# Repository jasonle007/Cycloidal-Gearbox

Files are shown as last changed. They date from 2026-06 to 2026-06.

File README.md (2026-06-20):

# Cycloidal-Gearbox
Documentation of the engineering design process of building a cycloidal drive. From idea, constraints, CAD, prototyping, and manufacturing the final product




## Design Requirements
The cycloidal drive project started as a project for my research lab (CoRE) where I am working to build a medical apparatus to experiment with human propioception. The device needed a strong motor/gearbox capable of producing enough torque to life a human leg from the sitting position, as well as the standing position.

Constraints included:
  - High torque capable of liting a human leg
  - Quiet gear box
  - Compact design
  - Minimal backlash
  - Durable

This led to the cycloidal drive design, which sastisfied these constrains and after discussions with my PI, gained approval for me to start researching and developing the drive.

## Design Process

### Cycloid Profile Generation
The cycloidal disk geometry was generated using standard cycloidal equations referenced from this SOLIDWORKS article [Building-a-Cycloidal-Drive](https://blog-assets.solidworks.com/uploads/sites/3/Building-a-Cycloidal-Drive-with-SOLIDWORKS.pdf).

The 4 main parameters were:

- Roller count (N) = 17
- Roller radius (Rr) = 6mm
- Rotor radius (R) = 50mm
- Eccentricity (E) = 1.8mm

With assistance from Claude, multiple geometries were evaluated to balance:
- Torque capacity
- Manufacturability
- Smooth operation

Cycloidal gear profile generation 133200


Based on the profile of the drive set by these parameters, they would define the rest of the assembly: housing, eccentric shaft, and output disk.

Note: This cycloidal drive design will utilize 2 cycloidal gears off set 180 from each other to balance out eccentric forces. Hence the need for an indicator of somekind 

### Housing
The housing would encase the entire assembly and roller pins for the gear profiles to engage with.

The roller pins with have a radius of 6mm and sit on a construction circle equal to the rotor radius of 50mm. These were the 2 critical dimensions for the housing and the rest of the design focused on fully encasing the assembly along with screw and threaded insert holes.



### Eccentric Shaft
The eccentric shaft's function is to engage the cycloidal profile with the roller pins. Creating the gear reduction and inverse rotation for the output pins.

The critical dimesions of the shaft is the eccentricity made by offsetting the center of the journal profile by 1.8mm. For this cycloidal drive design, the 2 cycloidal gears will sit 180 degrees offsetted from each other to cancel out the eccentric forces and reduce vibrations.



The red marks show the 1.8mm offset and in the center, both eccentric sections are offsetted by a total of 3.6mm. The shaft was designed to be printed in 3 seperate sections and joined together with 2 M4 screws traveling through the entire shaft. Shaft features raised borders to seperate each section and the shaft diameter was toleranced to be 19.9mm, which gives a snug fit of 0.1mm with the bearing.

### Output Disk
The output disk consists 2 sections joined together by screws and bearings to form the gear assembly. The output disk house the output pins whihc slots through output holes of the cycloid gear and transmit the gear's internal rotation into output torque. The first section is the base, where the input side sits and the second section is the cap where the output is transmitted.

The critical dimensions consist of the output pin diameter and the output pin construction circle, which can be set independently to the 4 main paramenters.





Both disks features a compliance cut around the center hole to give way to tight tolerances, reducing contact points and introducing flex to the contact, allowing for more forgiving fits of the output bearings. Additionally, threaded insert holes are modelled in for secure screw connections and repeatability.

## Key Engineering Challenges

### Bearing Fit
Initial prototypes produced undersized bearing bores due to PETG dimensional inaccuracies.

Solutions:
- Adjusted hole clearances
- Added compliance slots
- Tuned slicer XY compensation
- Performed iterative print testing

### Output Pins
Several output pin clearances were evaluated to reduce binding while minimizing backlash.

The final design calculated the output pin holes to be the (diameter + 2*eccentricity) to provide minimal backlass. Testing showed that approximately 0.2 mm radial clearance provided reliable operation. 

## Manufacturing

### Processes

- FDM 3D Printing with:
  - Prusa i3 MK3s+
  - PETg filament
 
- Slicing
  - XY - compensation to account for hole shrinkage as filament expands. In my case a value of -0.15mm worked best to pull back the walls of the holes by a diameter of 0.3mm, since past prototype prints would result in a hole shrinkage of 0.3mm
  - Elephant compensation to account for first layer filament spread. The first layer expanded roughly about 0.15mm outwards from the rest of the print, so the default value of 0.20mm worked best when printing PETg
 
### BOM
| Item | Note | Quantity | Price  | Total | Link |
| --- | --- | --- | --- | --- | --- |
| PETG Filament | Stronger and more secure structure | 2 | $0.00  | $0.00 | Already have |
| Shaft Bearings (20mm ID × 32mm OD × 10mm W, 10-pack) | For cycloid rotors and output disk (4) | 1 | $12.29 | $12.29 | [Link](https://www.amazon.com/uxcell-6804ZZ-Groove-Bearings-Shielded/dp/B082PWB7R5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) |
| Roller Bearings (4mm ID × 12mm OD × 4mm W, 20-pack) | For rollers (34) and output disk pins (12), 46 total  | 3 | $9.99  | $29.97 | [Link](https://www.amazon.com/uxcell-6804ZZ-Groove-Bearings-Shielded/dp/B082PWB7R5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) |
| Output Disk Bearings (35mm ID × 62mm OD × 14mm W, 2-pack) | For output disk to housing (2) | 1 | $9.99  | $9.99 | [Link](https://www.amazon.com/HiPicco-6007-2RS-Bearings-Bearing-Pre-Lubricated/dp/B0CH2WVW4V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) |
| M4 × 40mm Phillips Head Screws (15-pack) | For output disk pins (6) | 1 | $5.97  | $5.97 | [Link](https://www.amazon.com/Machine-Stainless-Assortment-Phillips-Furniture/dp/B0DLGT59V3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) |
| M4 × 65mm Hex Screws (10-pack) | For eccentric shaft (2) and housing cap (8), 10 total | 1 | $5.00  | $5.00 | [Link](https://www.amazon.com/Stainless-Machine-Hexagon-Fastener-Quantity/dp/B0CG1NMPCT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) |
| 4mm × 60mm Dowel Pins (20-pack) | For rollers (17) | 1 | $8.49  | $8.49 | [Link](https://www.amazon.com/uxcell-Cylindrical-Mechanical-Manufacturing-Installation/dp/B0DRSK8KVQ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) |
| M4 × 5mm L × 6mm OD Threaded Inserts (50-pack) | Inserts for housing and output disk connection (16) | 1 | $7.69  | $7.69 | [Link](https://www.amazon.com/uxcell-Knurled-Printing-Threaded-Embedment/dp/B0CTCT5TXZ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) |
| **Grand Total** | | | | **$79.40** | |

With filament supplied from the lab, the rest of the components came out to a total of $79.40. Added in extra costs of manufacturing and prototyping, this brings the total for this cycloidal drive to under $100. Note that many of these components are bought with higher quanities than needed so to build a second drive would only need a feew extra orders, bringing the projected cost of 2 fully assembled cycloidal drive to under $200.



## Results
- Reduction ratio: 17:1
- Maximum output torque: 40-50 Nm
- Number of design iterations: 20+
- Material: PETG
- Print time: 40+ hours (inclduing prototyping)

## Future Improvements
- Prototype with PLA and reduced infill
- Reduce housing wall width
- Finite element analysis
- Interference detection analysis

## Lessons Learned
This project strengthened my understanding of:

- Tolerance stack-up
- Design for additive manufacturing
- Bearing and shaft fits
- Iterative prototyping
- Mechanical power transmission
- Engineering tradeoff analysis

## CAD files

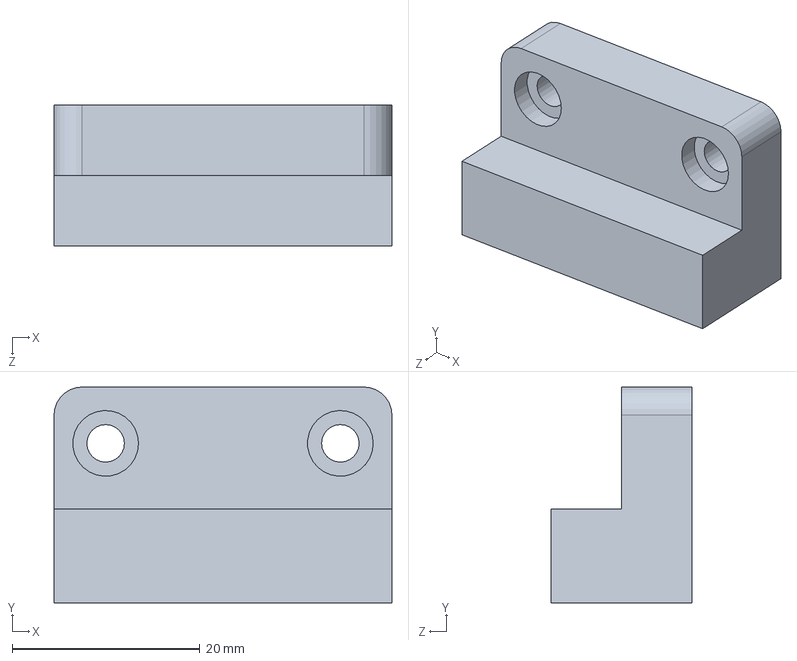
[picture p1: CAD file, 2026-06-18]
CAD/MotorMount.SLDPRT
36.0 x 23.0 x 15.0 mm

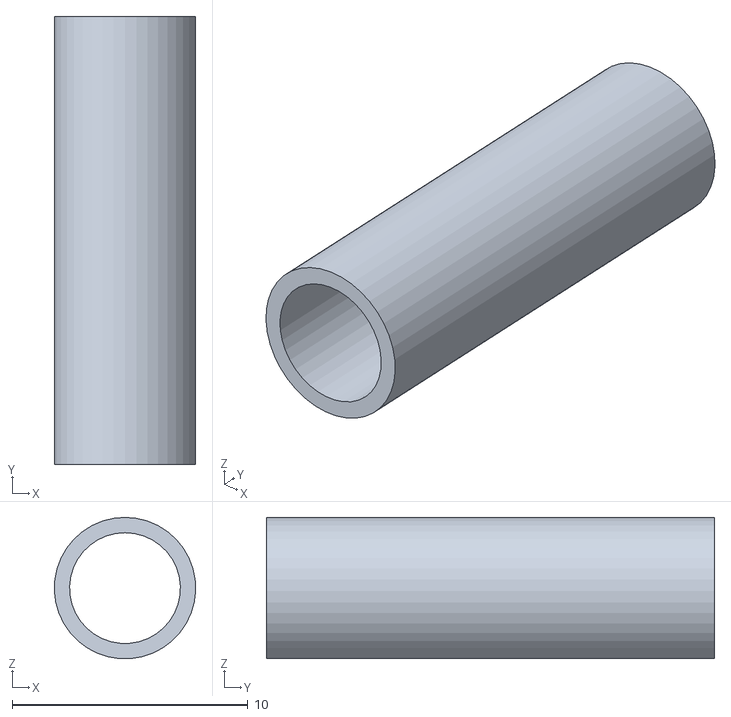
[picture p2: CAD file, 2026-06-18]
STL/Top Roller Spacers.STL
6.00 x 19.0 x 5.99

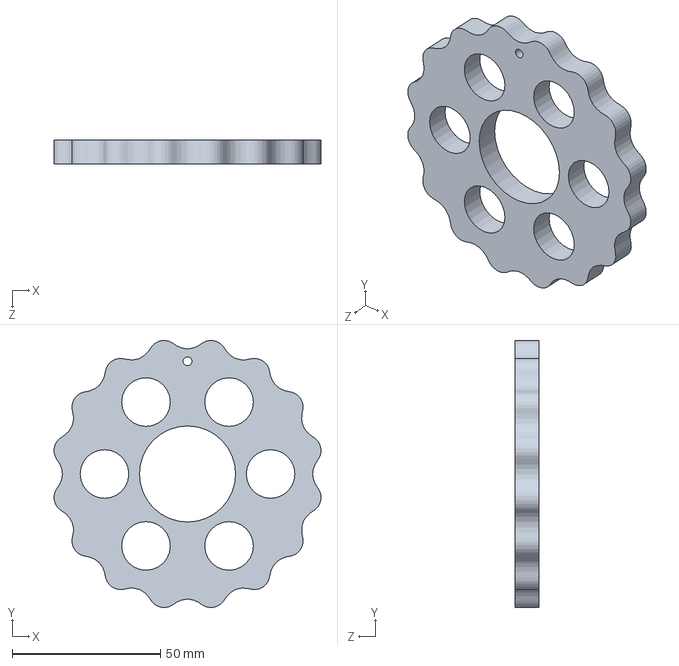
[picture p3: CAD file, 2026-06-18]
CAD/Cycloidal Internal Rotor.SLDPRT
90.0 x 90.0 x 8.00 mm

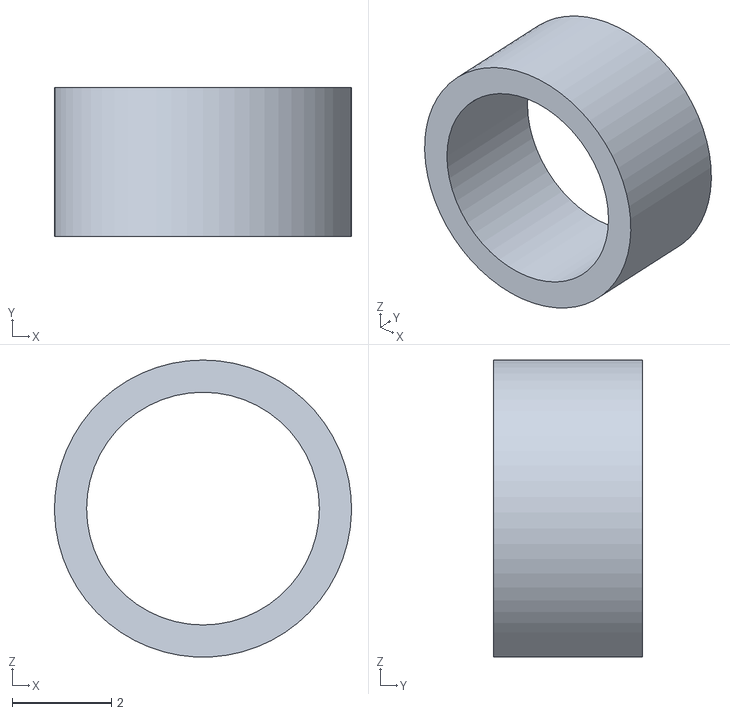
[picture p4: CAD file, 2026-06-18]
STL/3mm Output Disk Spacers.STL
6.00 x 3.00 x 6.00

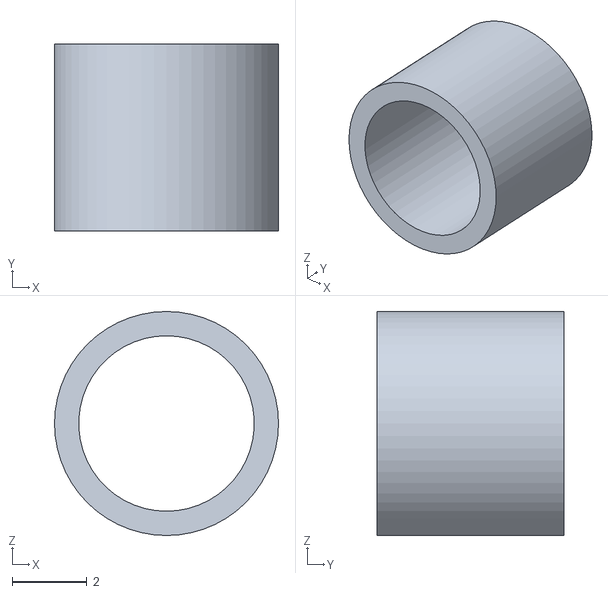
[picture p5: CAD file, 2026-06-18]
STL/5mm Output Disk Spacers.STL
6.00 x 5.00 x 6.00

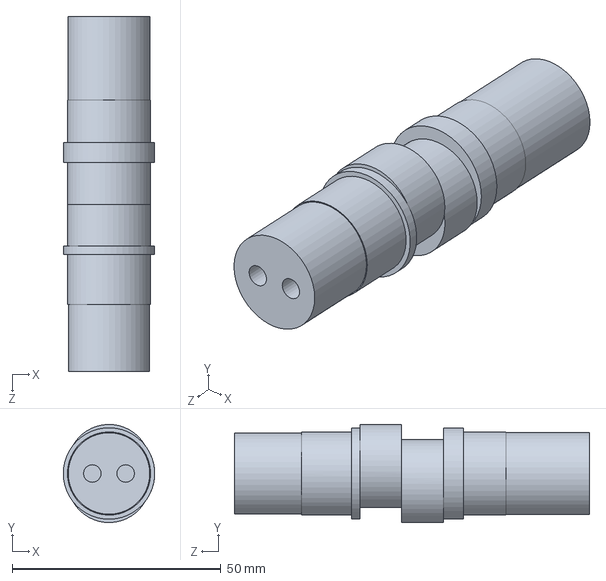
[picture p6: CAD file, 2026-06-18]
CAD/Eccentric Shaft.SLDPRT
21.9 x 23.5 x 85.0 mm

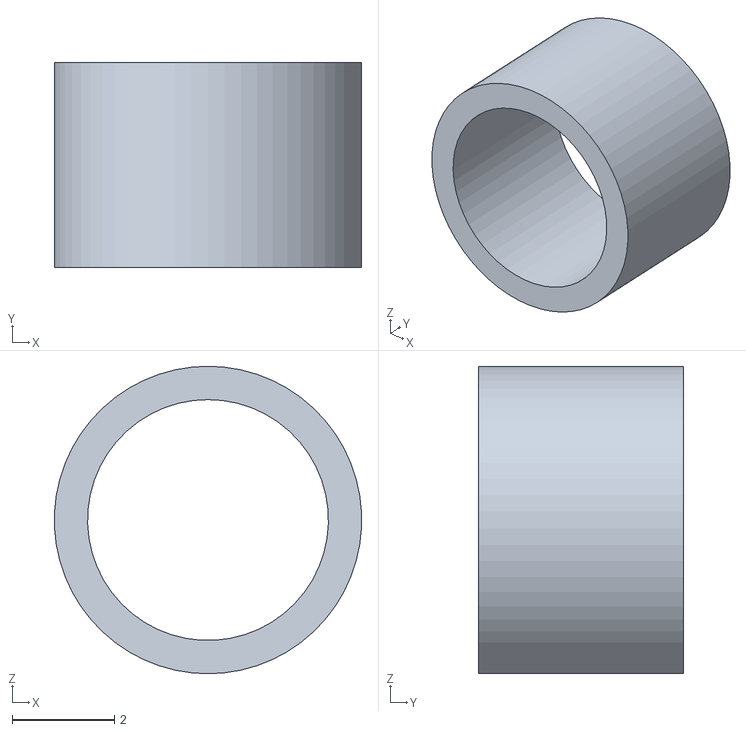
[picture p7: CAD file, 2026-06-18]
STL/Mid Roller Spacers.STL
5.99 x 4.00 x 6.00

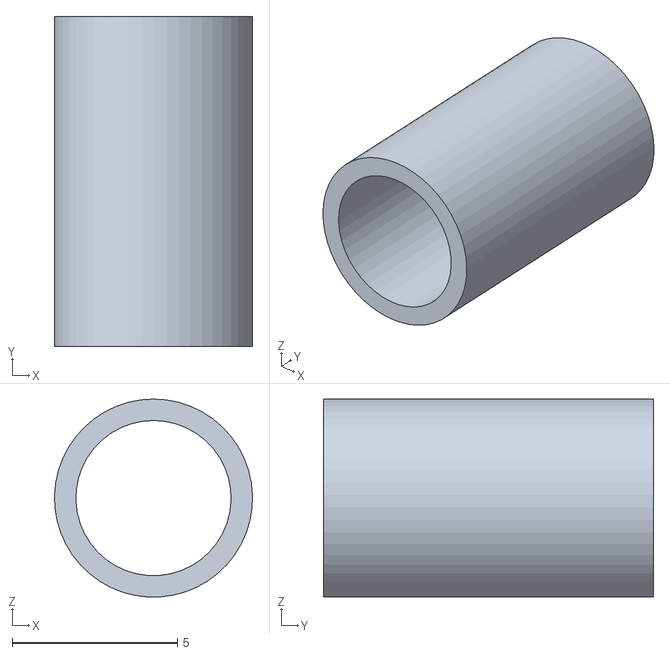
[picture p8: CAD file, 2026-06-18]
STL/10mm Output Disk Spacers.STL
6.00 x 10.0 x 5.99

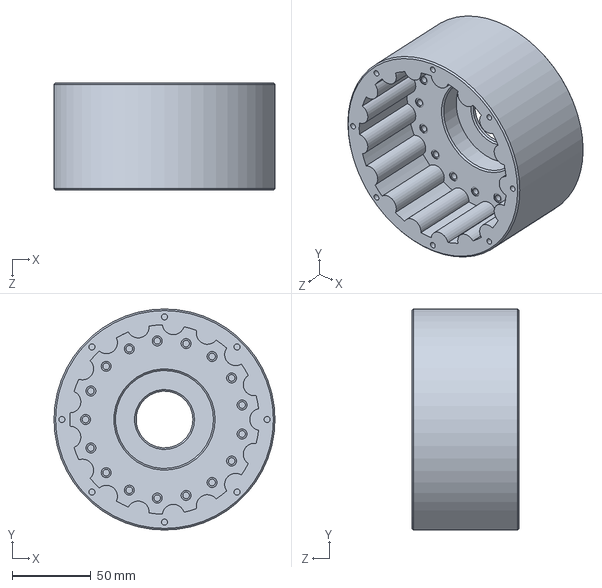
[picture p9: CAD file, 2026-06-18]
CAD/Housing.SLDPRT
140.0 x 140.0 x 68.0 mm

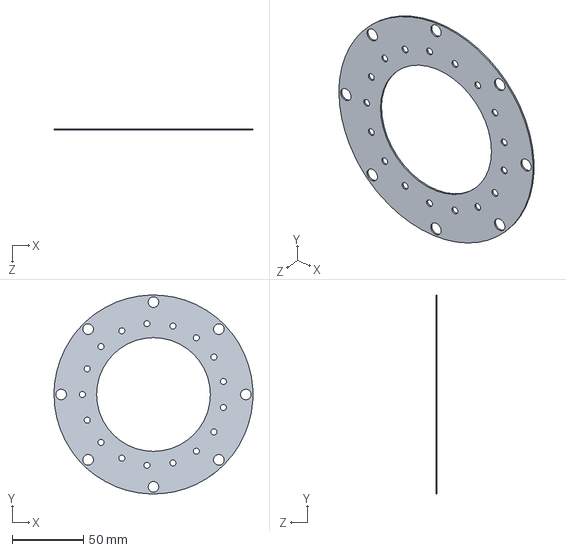
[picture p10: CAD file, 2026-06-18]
CAD/HousingCap.SLDPRT
140.0 x 139.9 x 1 mm

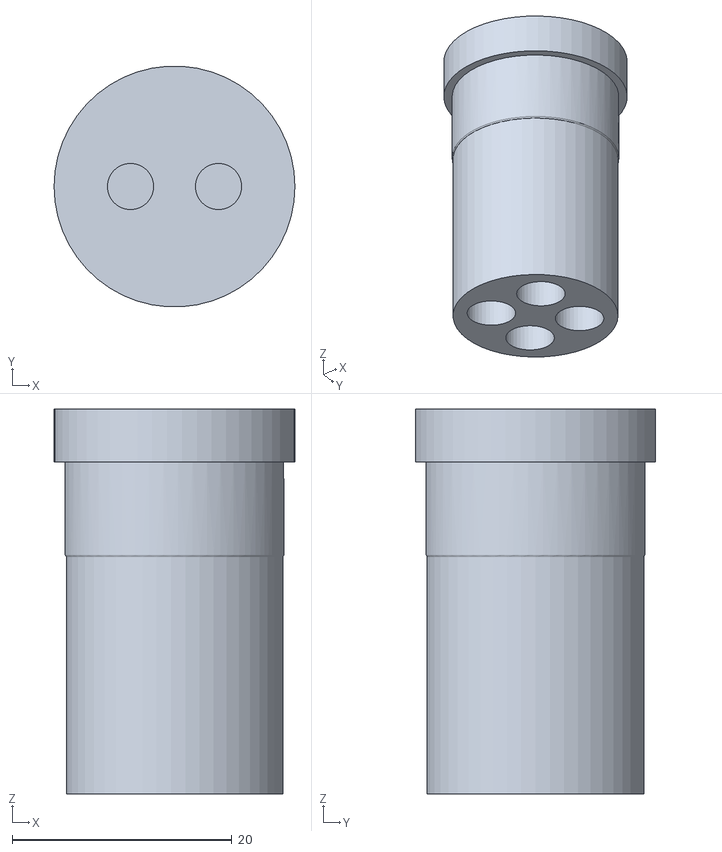
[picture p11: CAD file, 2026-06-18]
STL/Input Journal.STL
21.9 x 21.9 x 35.0

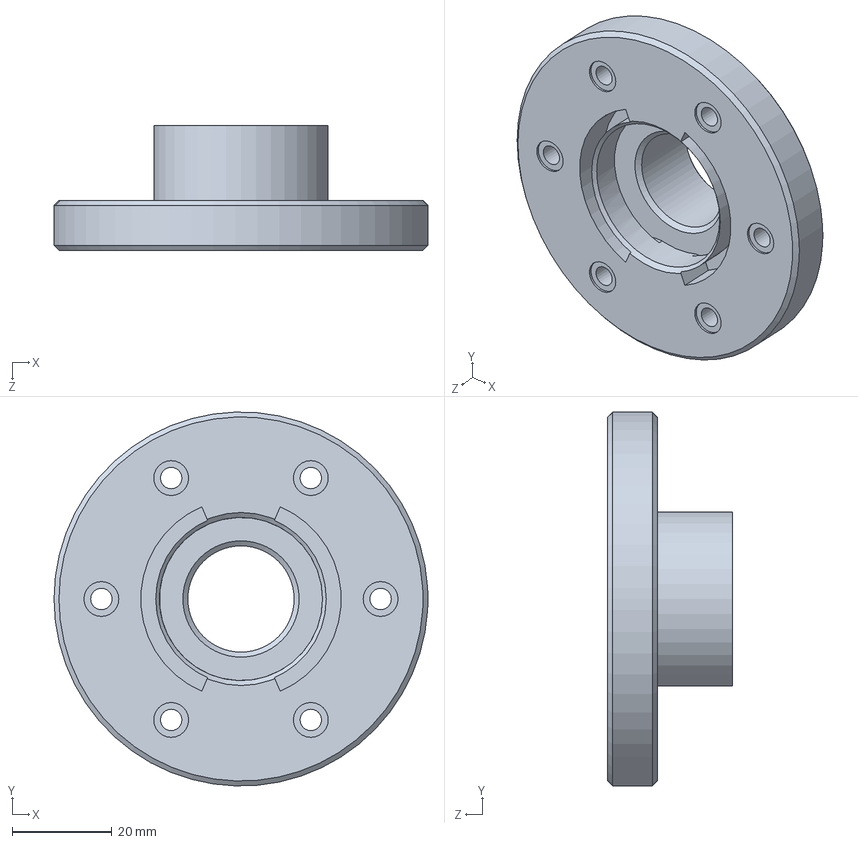
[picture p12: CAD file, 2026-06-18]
CAD/Output Disk.SLDPRT
75.0 x 75.0 x 25.0 mm

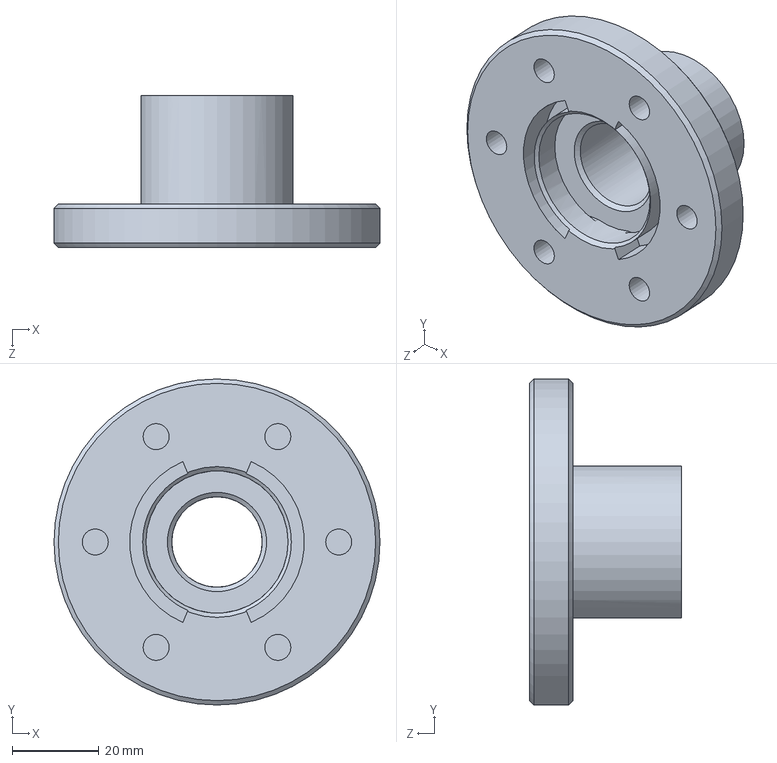
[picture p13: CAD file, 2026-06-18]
CAD/Output Disk Cap.SLDPRT
75.0 x 75.0 x 35.0 mm

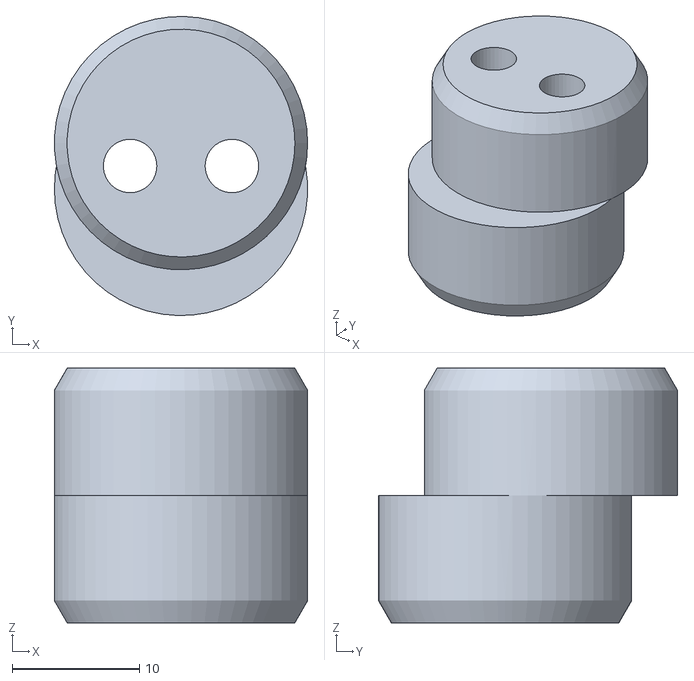
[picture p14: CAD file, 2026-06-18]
STL/Eccentric Section Journal.STL
19.9 x 23.5 x 20.0

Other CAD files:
CAD/Roller Spacers.SLDPRT
CAD/Output Disk Spacers.SLDPRT
STL/Bottom Roller Spacers.STL
STL/Allignment HousingCap.3mf
Hardware/5972K658_35mm shaft_Steel Ball Bearing.SLDPRT
Hardware/6656K105_Steel Ball Bearing.SLDPRT
Hardware/M4 Dowel or Screws.SLDPRT
STL/Allignment HousingCap.STL
STL/Cycloidal Internal Rotor.3mf
STL/Cycloidal Internal Rotor.STL
STL/Housing.3mf
STL/Housing.STL
STL/HousingCap.STL
STL/Output Disk Cap.STL
STL/Output Disk.STL
STL/Output Journal.STL

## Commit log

2026-06-18 Added CAD files
    Added CAD files of cycloidal drive assembly + hardware components
    [5972K658_35mm shaft_Steel Ball Bearing.SLDPRT, 6656K105_Steel Ball Bearing.SLDPRT, Cycloidal Internal Rotor.SLDPRT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]
2026-06-18 Rename 5972K658_35mm shaft_Steel Ball Bearing.SLDPRT to CAD/5972K658_35mm shaft_Steel Ball Bearing.SLDPRT
    [5972K658_35mm shaft_Steel Ball Bearing.SLDPRT]
2026-06-18 Added main assembly cad files
    Adde main assembly cad files
    [Cycloidal Internal Rotor.SLDPRT, Eccentric Shaft.SLDPRT, Housing.SLDPRT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]
2026-06-18 Added assembly hardware components
    Added assembly hardware components
    [5972K658_35mm shaft_Steel Ball Bearing.SLDPRT, 6656K105_Steel Ball Bearing.SLDPRT, M4 Dowel or Screws.SLDPRT]
2026-06-18 Collection of STL files
    Uploaded STL files for printing
    [10mm Output Disk Spacers.STL, 3mm Output Disk Spacers.STL, 5mm Output Disk Spacers.STL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]
2026-10-26 Revise results section with new torque specifications
    Updated reduction ratio and maximum output torque values in the results section.
